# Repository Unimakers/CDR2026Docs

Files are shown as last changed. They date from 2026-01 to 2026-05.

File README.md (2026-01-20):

---
title: "README & MICRODOC"
layout: default
---
# Documentation de l'association UniMakers pour la CDR2026

Table de contenu:
- [Documentation de l'association UniMakers pour la CDR2026](#documentation-de-lassociation-unimakers-pour-la-cdr2026)
  - [Comment créer une page ?](#comment-créer-une-page-)
  - [Comment afficher un modèle 3D](#comment-afficher-un-modèle-3d)

## Comment créer une page ?

Allez dans le dossier correspondant au thème de la page, 

exemple pour l'élec du robot principal: Robot/Elec/

Créez un nouveau fichier pour votre nouvelle page.

Rajoutez en haut du fichier:

```yaml
---
title: "Titre de votre page"
layout: technical
---
```

Utilisez `layout: technical` si vous souhaitez utiliser les modèles 3D ou le visualiseur kicad dans votre page, sinon utilisez `layout: default` pour réduire le temps de chargement de la page en supprimant les imports inutiles.

Les clés de définition doivent se trouver entre les deux `---`.
Après le deuxième `---` vous pouvez écrire le contenu de la page **en markdown**.

Vous pouvez rajouter un 
```yaml
has_children: true
```
si vous souhaitez faire de cette page une page de catégorie qui aura donc des sous-pages.

Pour mettre cette page en tant que sous-page dans une catégorie (et non à la racine) vous devez rajouter une clé `parent` et eventuellement une clé `grand_parent`:

La clé `parent` permettra de définir le parent direct de la page, la valeur doit etre le titre de la page parent.

Exemple, si vous créez une page dans la catégorie `Electronique` du `Robot` vous devrez définir la clé `parent` avec la valeur `Electronique`.

La clé `grand_parent` permettra de définir le grand parent de la page, c'est à dire la catégorie racine, la valeur doit etre le titre du grand parent.

Exemple, si vous créez une page dans la catégorie `Electronique` du `Robot` vous devrez définir la clé `grand_parent` avec la valeur `Robot`

Actuellement l'arbre des titres et catégories est:
```
Racine:
|-Présentation
|-Robot:
| |-Mécanique
| |-Stratégie
|-Pami:
| |-Mécanique
| |-Stratégie
|-Electronique
|-Programmation
| |-Déplacement
| |-Détection
```

Exemple pour créer une catégorie `Actionneurs` dans `Mécanique` sous `Robot` et ensuite créer une page `Pince`:

On crée le dossier `Robot/Meca/Actionneurs` (c'est mieux pour la lisibilité de trier les pages dans des dossiers, techniquement on pourrait tout laisser à la racine).

On crée le fichier `Robot/Meca/Actionneurs/Actionneurs.md`:
```md
---
title: Actionneurs
parent: Mécanique
grand_parent: Robot
has_children: true
layout: default
---
# Les actionneurs de notre robot
Le robot a besoin d'actionneurs pour fonctionner
```

On crée le fichier `Robot/Meca/Actionneurs/Pince.md`:
```md
---
title: Pince
parent: Actionneurs
grand_parent: Mécanique
has_children: true
layout: default
---
# La pince du robot
La pince du robot, nécessaire pour attraper.....
```

## Comment afficher un modèle 3D

Assurez vous d'avoir défini `layout: technical` au lieu de `layout: default`.

Dans votre code markdown rajoutez:
```md
<model-viewer alt="Texte de déscription du modèle 3D" src="url / chemin du modèle 3D" ar shadow-intensity="1" camera-controls touch-action="pan-y"></model-viewer>

Ou

{%raw%}{{%include model3D.html alt="Texte de description du modèle 3D" model="url / chemin du modèle 3D"%}}{%endraw%}
``` 
Le modèle 3D **doit** être en format GLTF / GLB.

## Comment utiliser le visionneur KiCad

Assurez vous d'avoir défini `layout: technical` au lieu de `layout: default`.

- Si vous ne souhaitez que le schématique:

Dans votre code markdown rajoutez:
```md
<kicanvas-embed src="chemin/vers/fichier.kicad_sch" controls="basic"></kicanvas-embed>
```

- Si vous souhaitez le schématique ET la PCB;

Dans votre code markdown rajoutez:
```md
<kicanvas-embed controls="full">
<kicanvas-source src="chemin/vers/fichier.kicad_sch"></kicanvas-source>
<kicanvas-source src="chemin/vers/fichier.kicad_pcb"></kicanvas-source>
</kicanvas-embed>
```

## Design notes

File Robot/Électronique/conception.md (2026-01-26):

---
title: "La conception de la carte"
parent: Elec
layout: technical
---
# La conception de la carte

## 1. Introduction à la conception

Cette section a pour objectif de présenter les principes et choix ayant guidé la conception de la carte électronique du robot. Elle se concentre exclusivement sur les aspects liés à la **conception matérielle et architecturale** de la carte, indépendamment de son utilisation ou de son intégration logicielle, qui sont traitées dans d’autres documents.

La carte a été conçue dans le cadre de la Coupe de France de Robotique, avec pour objectif principal de constituer une solution **fiable, compacte et pérenne**, capable d’être réutilisée sur plusieurs années sans modification majeure. Les contraintes mécaniques du robot étant volontairement figées sur le long terme, la conception de la carte s’inscrit dans cette logique de stabilité et de durabilité.

Un choix structurant de cette conception est l’adoption d’une **architecture tout-en-un**. L’ensemble des fonctions auparavant réparties sur plusieurs cartes distinctes (traitement, capteurs, actionneurs, communication et alimentation) est regroupé sur une seule carte électronique. Cette approche vise à réduire la complexité globale du système, à limiter le câblage interne et à améliorer la fiabilité, en particulier dans un contexte de compétition où les vibrations, les chocs et les faux contacts sont des sources fréquentes de défaillance.

La conception repose également sur une **segmentation fonctionnelle claire**, matérialisée par l’utilisation de plusieurs microcontrôleurs spécialisés. Cette répartition permet de découpler les tâches critiques, de simplifier le développement et le débogage, et d’améliorer la robustesse globale du système, tout en conservant une vision centralisée du fonctionnement du robot.

Enfin, la carte a été pensée pour rester **évolutive et maintenable**. Des interfaces d’extension sont prévues afin de permettre l’ajout de fonctionnalités futures sans remise en cause de l’architecture existante. Les choix réalisés lors de la conception privilégient la lisibilité du schéma, la clarté du routage et l’accessibilité des composants critiques, afin de faciliter la compréhension, la maintenance et les évolutions ultérieures.

## 2. Schéma électronique

### a. Présentation du schéma global

Le schéma électronique a été réalisé sous **KiCad** et est volontairement regroupé sur **une seule feuille au format A2**. Ce choix a été fait afin de conserver une **vision globale immédiate** de l’ensemble de la carte, sans navigation entre plusieurs pages, ce qui facilite la compréhension, la relecture et la maintenance du schéma.

Le schéma est organisé en **blocs fonctionnels clairement délimités**, chaque bloc correspondant à une partie précise de la carte (alimentation, microcontrôleurs, drivers, communication, LED, connecteurs, etc.). Cette organisation visuelle permet d’identifier rapidement le rôle de chaque sous-ensemble tout en conservant une cohérence globale.

Les interconnexions entre les différents blocs sont réalisées à l’aide de **labels globaux**, limitant l’encombrement visuel et améliorant la lisibilité du schéma, tout en restant cohérentes avec le routage du PCB.

### b. Description par parties

#### Alimentation

L’alimentation de la carte repose sur une **distribution en 24/12/5/3.3 V**, qui constitue les tensions centrales du système. Ces tensions sont générées à partir de la batterie via des **convertisseurs de puissance** de type :
- **TSR 2433 / TSR 2450**
- **TEN 50-2411 / TEN 50-2412**

Un convertisseur est dédié spécifiquement à l’**alimentation de la logique**, afin d’assurer une tension stable pour les microcontrôleurs et les circuits de communication.

Les masses sont **communes**, ce qui simplifie la conception tout en assurant une référence électrique cohérente sur l’ensemble de la carte.

Le découplage est principalement assuré **au plus proche des charges**, notamment au niveau des moteurs pas à pas, des servomoteurs et des pompes, afin de limiter les effets des appels de courant et des perturbations générées par les charges inductives.

#### Traitement

La partie traitement repose sur **trois microcontrôleurs** de type **XIAO ESP32-S3** :
- deux XIAO ESP32-S3+,
- un XIAO ESP32-S3.

Chaque microcontrôleur dispose de ses propres lignes de **reset et de boot**, permettant une programmation et un débogage indépendants.

L’alimentation des microcontrôleurs est assurée par le convertisseur dédié à la logique, garantissant une tension stable et isolée des perturbations liées à la puissance.

Même si la hiérarchie maître/esclave n’est pas explicitement matérialisée sur le schéma, les liaisons internes et le découpage fonctionnel traduisent le rôle central du microcontrôleur principal dans la coordination du système.

#### Communication

Les communications internes reposent sur des **liaisons UART point à point**, représentées sur le schéma à l’aide de **labels globaux**, reliant le microcontrôleur principal aux microcontrôleurs dédiés aux capteurs et aux actionneurs.

Un **bus I²C** est également présent et clairement identifié par des labels. Les résistances de **pull-up I²C sont intégrées directement sur la carte**, ce qui permet une utilisation immédiate du bus sans ajout externe.

La communication sans fil est rendue possible par un **module XBee optionnel**, connecté via un **connecteur câblé**. Ce module n’est pas indispensable au fonctionnement du robot, mais permet la transmission d’informations et le paramétrage avant match.

Les interfaces de communication et les connecteurs externes sont regroupés dans des zones dédiées du schéma, facilitant leur identification et leur intégration sur le PCB.

#### Puissance

La partie puissance inclut la gestion directe des actionneurs du robot. Les **moteurs pas à pas** sont pilotés par des **drivers TMC2209**, intégrés directement sur la carte. Ce choix a été motivé par :
- la simplicité d’utilisation,
- les habitudes de l’équipe,
- le fonctionnement silencieux de ces drivers.

Les **servomoteurs et les pompes** sont commandés directement par la carte, sans étage intermédiaire spécifique. Aucune protection active dédiée aux charges inductives n’est intégrée, la conception reposant principalement sur le découplage et la gestion logicielle des activations.

Les éléments de puissance sont regroupés dans des zones dédiées du schéma, clairement séparées des parties logiques et de communication, afin de limiter les interactions et de faciliter la compréhension de l’architecture.

### c. Choix des composants principaux

#### Microcontrôleurs

Le choix des XIAO ESP32-S3 repose principalement sur les **habitudes de l’équipe** ainsi que sur la **disponibilité du matériel** déjà possédé par l’association. L’utilisation de trois microcontrôleurs permet d’augmenter le nombre de cœurs disponibles et de **programmer chaque microcontrôleur indépendamment**, ce qui simplifie la compréhension, le développement et le débogage du code.

Ces microcontrôleurs sont considérés comme **critiques** dans la conception, leur défaillance entraînant l’arrêt du système.

#### Drivers moteurs

Les drivers **TMC2209** ont été sélectionnés pour leur facilité d’intégration, leur fiabilité et leur fonctionnement silencieux. Ils sont directement implantés sur la carte afin de réduire le câblage et d’améliorer la robustesse globale du système.

#### Écran

L’interface utilisateur repose sur un **écran tactile TFT utilisant une communication SPI**. L’écran ne génère pas de contrainte particulière au niveau du schéma électronique et reste **optionnel**. En cas d’absence ou de défaillance de l’écran, le système peut fonctionner en mode dégradé grâce aux boutons physiques prévus sur la carte.

## 3. Conception du PCB

### a. Dimensions et forme de la carte
- Forme générale de la carte
- Dimensions
- Contraintes d’intégration mécanique
- Orientation dans le robot

### b. Règles de routage spécifiques
- Organisation générale du routage
- Autoroute centrale pour les signaux
- Gestion et continuité du plan de masse
- Séparation des zones de puissance
- Zone dédiée au **24 V**

### c. Placement des composants critiques
- Écran
- Microcontrôleurs
- Connecteurs d’extension I²C
- Justification des placements

### d. Connecteurs
- Connecteurs servomoteurs
- Connecteurs GPIO
- Connecteurs d’extension
- Connecteur d’alimentation
- Choix des types de connecteurs

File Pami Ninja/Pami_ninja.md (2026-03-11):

---
title: "Pami Ninja"
layout: technical
nav_order: 1
has_children: true
---

# Présentation Technique : Le PAMI Ninja (Saison 2026)

## 1. Introduction
Le **PAMI Ninja** (Petit Actionneur Mobile Indépendant) est une unité robotique autonome auxiliaire conçue pour opérer spécifiquement dans la zone surélevée du terrain : **le Grenier**. 

Complémentaire au robot principal, il joue un rôle stratégique crucial en manipulant les ressources en hauteur pour maximiser le score de l'équipe grâce à sa grande agilité et son système de préhension par le vide.

---

## 2. Missions et Objectifs Stratégiques
Le PAMI Ninja est spécialisé dans la manipulation de haute précision en espace restreint. Ses objectifs sont hiérarchisés comme suit :

* **Libération des ressources :** Vidage des quatre "frigos" du grenier pour rendre les caisses de noisettes accessibles aux robots au sol.
* **Substitution symbolique :** Remplissage des frigos avec des caisses vides (noires) récupérées dans les zones de chargement.
* **Action finale "À table !" :** En fin de match, ralliement du garde-manger pour valider les points d'occupation ou activation du mécanisme symbolique.

---

## 3. Spécifications et Contraintes
Pour garantir son homologation, le PAMI Ninja respecte strictement les limites fixées par le règlement de la CDR 2026 :

### 3.1 Gabarit et Mobilité
* **Configuration au départ :**
    * Périmètre max : **600 mm**
    * Hauteur max : **150 mm**
* **Configuration en match (déployé) :**
    * Périmètre max : **700 mm**
    * Hauteur max : **350 mm**

### 3.2 Caractéristiques Physiques
* **Masse :** Limite stricte de **1,5 kg**.
* **Énergie :** Alimentation autonome avec protection intégrée pour batterie LiPo.
* **Intelligence :** Système d'évitement d'obstacles embarqué et autonomie décisionnelle totale.

---

## 4. Environnement de Jeu et Valorisation
Le PAMI Ninja évolue dans un écosystème spécifique où chaque action est déterminante pour le score final.

### 4.1 Zone d'évolution
* **Le Grenier :** Une surface de 45 \ 180 cm interdite aux robots principaux.
* **Zone de départ :** Un carré de 20 \ 20 cm situé en hauteur, imposant un design compact dès le déploiement.

### 4.2 Barème de points (Extraction & Remplissage)
**Calcul des points :**
* Chaque frigo vidé : **+2 points**
* Chaque frigo rempli (caisses vides) : **+5 points**

*Note : Ces points sont comptabilisés pour les deux équipes lors du bilan de fin de match.*

---

## 5. Architecture de l'Unité
Le PAMI Ninja est décomposé en trois modules principaux détaillés dans cette documentation :
1.  **Mécanique :** Châssis modulaire MakerBeam et système de ventouse.
2.  **Électronique :** Gestion de la puissance et capteurs de proximité.
3.  **Programmation :** Algorithmes de navigation et logique d'état.

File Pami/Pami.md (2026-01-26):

---
layout: technical
title: Pami
has_children: true
nav_order: 1
---
# Nos PAMIs

<model-viewer alt="PAMI" src="./Meca/FichiersGLTF/ExportPAMIUniWIP.glb" ar style="width:80%; height:400px" shadow-intensity="1" camera-controls min-field-of-view="2deg"></model-viewer>

## Qu'est-ce qu’un PAMI ?

Un **PAMI**, ou *Petit Actionneur Mobile Indépendant*, est un petit robot **autonome** utilisé en complément du robot principal pendant un match. Il peut être lancé au début ou en cours de partie, et il doit être capable de se déplacer par lui-même, même s’il peut être aidé ou contrôlé par les robots de son équipe pendant le match.

Comme les robots classiques, un **PAMI** doit respecter des règles strictes de sécurité et de construction : système d’arrêt d’urgence, détection d’obstacles, sécurité des batteries, etc. Il doit aussi pouvoir fonctionner quelle que soit la couleur de l’équipe.

Un **PAMI** ne suffit pas à lui seul pour homologuer une équipe, mais il doit être homologué pour avoir le droit de participer à un match. Si le robot principal ne peut pas rouler, les PAMIs peuvent quand même jouer seuls, à condition que tout soit homologué et que le robot principal soit present mas static.

## Quel est son role ?

Chaque année, les PAMIs ont des rôles différents, mais leur objectif reste le même : rapporter des points supplémentaires à l’équipe.

Pour cette édition, il existait deux types de PAMIs :

- **La Superstar**

    La Superstar devait monter sur la scène et avancer le plus loin possible dessus pour marquer un maximum de points. Une fois bien placée, elle pouvait activer un actionneur pour « danser ».

- **Les Groupies***

    Les Groupies, quant à elles, devaient se positionner dans des zones spécifiques situées juste devant la scène. Elles aussi pouvaient activer un actionneur pour effectuer une danse.

- **Système de points lié aux PAMIs**

    **5** points sont accordés par Groupie présente dans la zone de fosse (devant la scène) à la fin du match.

    **5** points supplémentaires sont donnés si la Superstar est sur la scène à la fin du match.

     Enfin, **10** points bonus sont attribués si tous les PAMIs dansent ensemble à la fin du match ("font la fête").

## Contraintes techniques

| Critère |  Valeur |
|---|---|
| 📦 **Taille max au départ**  | `150 mm × 450 mm` |
| 📏 **Hauteur** | entre `60 mm` et `150 mm` |
| ⚖️ **Masse maximale** | `1,5 kg` |
| 🎯 **Zone autocollant** | `30 mm × 30 mm` (visible en vue de dessus) |
| 🚀 **Déploiement autorisé** | jusqu’à `+100 mm` en périmètre, `350 mm` en hauteur |
| 🔋 **Autonome** | Déplacement + action sans contact direct |

si vous vouler plus d'information voici le lien en direction des diferents reglement:     
<a href="https://www.eurobot.org/wp-content/uploads/2024/10/Eurobot_General_Rules.pdf" target="_blank">
  Description
</a>

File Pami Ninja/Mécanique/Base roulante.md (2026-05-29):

---
title: "Base roulante"
layout: technical
grand_parent: Pami Ninja
parent: Mécanique
---

# Section mécanique : Base roulante

## 1. Philosophie de conception
La base roulante du **PAMI Ninja** a été conçue pour offrir un compromis idéal entre **rigidité structurelle**, **précision de déplacement** et **accessibilité technique**. 

Initialement, nous avions envisagé un châssis monobloc en impression 3D. Cependant, pour faciliter l'intégration des composants et la maintenance sur le terrain, nous avons opté pour une structure modulaire en **MakerBeam**.

<model-viewer alt="premier prototype" src="../model/premier_prototype.glb" ar style="width:80%; height:400px" shadow-intensity="1" camera-controls min-field-of-view="2deg"></model-viewer>

*Premier design de chassis*

<model-viewer alt="base en MakerBeam" src="../model/makerbeam.gltf" ar style="width:80%; height:400px" shadow-intensity="1" camera-controls min-field-of-view="2deg"></model-viewer>

*Base en MakerBeam*

---

## 2. Structure et Châssis
Le squelette du robot repose sur des profilés en aluminium de 10 \ 10 mm (MakerBeam).

### 2.1 Avantages du système MakerBeam
* **Modularité :** Permet d'ajuster la position des capteurs et des supports sans réimprimer de pièces.
* **Robustesse :** L'aluminium offre une rigidité bien supérieure au plastique face aux collisions éventuelles.
* **Maintenance :** Les faces en acrylique sont fixées via des **vis à tête carrée** glissées dans les rainures et maintenues par des écrous standards. 

> **Accessibilité :** Chaque face est démontable en dévissant simplement 8 écrous, permettant un accès complet à l'électronique interne en moins de 30 secondes sans fragiliser la structure porteuse.

---

## 3. Motorisation et Cinématique
La base utilise une configuration à deux roues motrices classiques avec des moteurs pas-à-pas.

| Composant | Détails techniques |
| :--- | :--- |
| **Moteurs** | Moteurs pas-à-pas (Stepper) pour une précision millimétrée |
| **Transmission** | Montage en **prise directe** sur l'axe moteur (évite le backlash) |
| **Type de roues** | Roues classiques en silicone à haute adhérence |
| **Support** | Fixation directe sur la plaque inférieure du châssis |

### 3.1 Intégration du système de préhension
La face avant présente une particularité : un évidement a été pratiqué dans la MakerBeam supérieure. Ce passage est dédié au **mécanisme de la ventouse**, permettant au bras et au tuyau de vide de se déployer vers l'extérieur pour manipuler les éléments de jeu.

---

## 4. Analyse de Masse et Stabilité
L'un des défis majeurs pour un PAMI est sa stabilité lors des phases d'accélération et de freinage brusques.

* **Centre de Gravité bas :** En fixant les moteurs (les composants les plus lourds) directement sur la plaque inférieure, nous abaissons au maximum le centre de gravité.
* **Répartition des masses :** Le choix de l'aluminium pour le cadre et de l'acrylique pour les parois permet de garder une structure légère en périphérie tout en concentrant le poids au niveau du plancher.
* **Impact dynamique :** Cette configuration réduit le moment d'inertie et limite l'effet de "tangage" lors des changements de direction, garantissant que la ventouse reste alignée avec sa cible.

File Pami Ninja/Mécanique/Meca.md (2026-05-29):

---
title: "Mécanique"
layout: technical
parent: "Pami Ninja"
nav_order: 2
has_children: true
---

# Partie mécanique du PAMI Ninja

Le PAMI Ninja est constitué de deux sous-ensembles mécaniques principaux. Le premier est une base roulante assurant le déplacement du robot et l’intégration des composants nécessaires à son fonctionnement. Le second correspond aux actionneurs, qui permettent d’interagir avec les éléments présents dans le grenier. Une description détaillée de ces deux parties sont accessible via le menu déroulant situé à gauche.

Voici à quoi ressemble le PAMI Ninja dans son ensemble:
<div style="display: flex; justify-content: space-around; flex-wrap: wrap;">
<model-viewer alt="premier prototype" src="../model/assemblage_pami_ninja.gltf" ar style="width:80%; height:400px" shadow-intensity="1" camera-controls min-field-of-view="2deg"></model-viewer>
</div>

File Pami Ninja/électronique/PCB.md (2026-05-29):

---
title: "PCB"
layout: technical
grand_parent: Pami Ninja
parent: Électronique
has_children: false
---

Voici le PCB de notre carte électronique ci dessous:

<kicanvas-embed controls="full">
<kicanvas-source src="../électronique/pcb&schéma/carte_pami_ninja.kicad_pcb"></kicanvas-source>
</kicanvas-embed>

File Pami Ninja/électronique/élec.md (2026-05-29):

---
title: "Électronique"
layout: technical
parent: "Pami Ninja"
nav_order: 2
has_children: true
---

# Électronique

La partie électronique parle de la carte que nous avons dû concevoir pour faire fonctionner le PAMI Ninja. Cette partie est décomposée en deux éléments qui sont accessible via le menu déroulant situé à gauche :

- Le schéma électrique réalisé sur le logiciel KiCad.
- Le PCB (circuit imprimé) qui permet le fonctionnement de la carte.

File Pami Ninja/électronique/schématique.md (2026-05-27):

---
title: "Schématiques"
layout: technical
grand_parent: Pami Ninja
parent: Électronique
has_children: false
---

# Conception du Schématique Électronique

## 1. Présentation générale

Avant de dessiner physiquement la carte (le PCB), on a réalisé le **schématique** sur le logiciel **KiCad**. Cette étape constitue le plan logique du circuit, permettant de définir les composants à utiliser ainsi qu'à visualiser les différentes connexions entre eux.

Pour garantir la fiabilité du système, on s'est appuyé sur la documentation des anciennes cartes de l'association ainsi que sur l'accompagnement des professeurs du MakerSpace.

Voici donc le dit schématique:

<kicanvas-embed controls="full">
<kicanvas-source src="../électronique/pcb&schéma/carte_pami_ninja.kicad_sch"></kicanvas-source>
</kicanvas-embed>

## 2. Architecture du circuit 

Pour rendre le schéma plus clair et modulaire, on a fait le choix de le découper en plusieurs blocs fonctionnels. Chacun a un rôle précis dans le fonctionnement du PAMI Ninja :

* **Batterie :** Ce bloc gère l'arrivée directe de l'énergie. C'est le point d'entrée de la puissance générale de la carte qui sera ensuite distribuée et régulée.
* **Microcontrôleur :** Bien qu'il ne soit pas enfermé dans un bloc visuel, c'est le cœur du système (basé sur un module ESP32). Il centralise toutes les connexions logiques : il exécute le programme de match, traite les données reçues des capteurs et donne les ordres d'action.
* **Driveurs moteur pas à pas :** Cette partie gère l'interface de puissance pour les mouvements. Elle permet au microcontrôleur de piloter les moteurs des roues avec précision pour assurer les déplacements du robot sur le plateau.
* **Pompe :** Ce bloc est dédié spécifiquement à la gestion du système de la pompe de notre robot. Il commande l'activation de la pompe nécessaire à la préhension des caisses de noisettes par la ventouse.
* **Actionneurs :** Ce bloc regroupe la commande des autres éléments mécaniques mobiles, comme le capteur à ultrasaon qui permets de détecter si quelque chose se rapproche afin d'éviter toute collision ou comme la tirette qui nous permettra de mettre en route nos robots à chaque début de match.
* **Extensions :** Ce bloc permet d'ajouter des fonctionnalités supplémentaires ou des capteurs externes comme le servo moteur permettant de gérer l'inclinaison du bras. Il offre une flexibilité pour faire évoluer le robot sans modifier le cœur de la carte.

## 3. Réflexion technique

L'étude des versions précédentes a mis en avant l'importance d'avoir un schéma propre et bien compartimenté. Cette organisation permet de ne pas surcharger la vue globale et de limiter les erreurs de câblage lors de la conception.

Grâce aux conseils des professeurs, on a pu s'assurer que l'isolation entre les blocs de puissance et la logique était bien respectée. Cette rigueur dans la conception du schématique est indispensable pour que le robot soit robuste et qu'il ne subisse pas d'interférences durant les 90 secondes de match.

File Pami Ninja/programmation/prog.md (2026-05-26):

---
title: "Programation"
parent: "Pami Ninja"
layout: technical
---

# Programation

## Introduction

Ce code contrôle un robot mobile pour une compétition (type Coupe de Robotique / Eurobot).  
Il gère :

- Deux moteurs pas à pas avec driver (TMC2209 ou similaire)
- Un servo-moteur sur PCA9685
- Une pompe et une électrovanne via PCF8574
- Une tirette de démarrage
- Un interrupteur de côté (Jaune / Bleu)

Le robot exécute une stratégie autonome une fois la tirette retirée.

---

## Configuration Matérielle

### Broches ESP32

| Broche | Définition | Fonction | Commentaire |
|---|---|---|---|
| GPIO2  | `STEP_D` | Step moteur droit | |
| GPIO1  | `DIR_D` | Direction moteur droit | |
| GPIO4  | `STEP_G` | Step moteur gauche | |
| GPIO3  | `DIR_G` | Direction moteur gauche | |
| GPIO9  | `EN_PIN` | Enable moteurs | LOW = actif |
| GPIO8  | `TIRETTE` | Tirette de démarrage | LOW = présente |
| GPIO7  | `SWITCH` | Interrupteur côté | LOW = Jaune |

**I2C** : SDA = GPIO5 (D4), SCL = GPIO6 (D5)

### Périphériques I2C

- **PCA9685** : Adresse `0x40` → Contrôle du servo (canal 0 - J13)
- **PCF8574AT** : Adresse `0x20` → Contrôle Pompe + Électrovanne

---

## Bibliothèques Utilisées

```cpp
#include <Arduino.h>
#include <Wire.h>
#include <Adafruit_PWMServoDriver.h>

C++

#define VITESSE_MOTEUR 800        // Microsecondes entre pas (plus bas = plus rapide)
#define NB_MINI_PAS 5

// Calibration odométrie (calibrée sur le terrain)
#define STEPS_PER_REV     3232
#define WHEEL_CIRC_CM     45.87f
#define WHEELBASE_CM      8.20f

#define CM_EN_PAS(cm)     ((int)((float)(cm) / WHEEL_CIRC_CM * STEPS_PER_REV))
#define DEG_EN_PAS(deg)   ((int)((float)(deg) / 360.0f * (float)M_PI * WHEELBASE_CM / WHEEL_CIRC_CM * STEPS_PER_REV))
```

# Fonctions de Contrôle

1. **Pompe et Électrovanne** (PCF8574)

    Le PCF8574 est en open-drain : écrire 0 = actif (LOW), écrire 1 = inactif.
    void pompeOn();
    void pompeOff();
    void evOn();
    void evOff();

2. **Servo** (PCA9685)

    #define SERVO_J13_CH 0
    #define SERVO_MIN 150
    #define SERVO_MAX 500
    void setServoAngle(int angle); // Angle entre 0 et 180°
    updateServoFromSwitch(); // Position selon l'interrupteur

3. **Mouvements de Base**

La fonction **rotate()** intègre une rampe d’accélération / décélération pour plus de fluidité et de précision.

* avancer(steps) / avancerCm(float cm)

* reculer(steps) / reculerCm(float cm)

* tournerDroite(steps) / pivoterDroite(float deg)

* tournerGauche(steps) / pivoterGauche(float deg)

* Stratégies
  Deux stratégies miroirs sont implémentées en fonction du coté sur lequel on était :

  * strategieJaune()

  * strategieBleu()

  Le choix est fait automatiquement selon l’état de l’interrupteur SWITCH.
  Chaque stratégie contient :

* Petite manœuvre de départ

* Séquence de déplacements précis (avances, reculs, rotations)

* Actions finales avec le servo

* Boucle infinie d’oscillation du servo en fin de match (effet visuel / signal)

## Fonction setup()

* Initialisation de la communication I2C (Wire.begin(5, 6))

* Configuration du PCA9685 (fréquence 50 Hz)

* Configuration des broches GPIO

* Scan complet du bus I2C (affiché dans le moniteur série)

* Mise à l’état initial : pompe et EV éteintes, servo à 90°

* Initialisation du PCF8574 (toutes sorties relâchées)

## Fonction loop()
Fonctionnement classique d’un robot de compétition :

1. Mise à jour continue de la position du servo selon l’interrupteur

2. Attente de la tirette

3. Détection du côté (Jaune ou Bleu)

4. Exécution de la stratégie correspondante

5. Attente de remise de la tirette pour permettre un nouveau départ

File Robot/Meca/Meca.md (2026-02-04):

---
title: "Mécanique"
parent: "Robot"
layout: technical
---
## Le châssis 🧰

### La Base 🛠️
Pour la base du robot, nous avons opté pour un châssis différentiel, c'est à dire un châssis à deux roues motrices. Ce type de châssis est plus simple à mettre en œuvre et plus facile de prise en main, aussi bien pour nous que pour les étudiants de première année car il offre une excellente maniabilité, notamment pour réaliser des rotations sur place et des déplacements précis sans nécessiter une mécannique complexe.

### La Compartimentation 🧩
La structure extérieur du châssis étant complétée, nous avons choisi de le compartiementer en plusieurs espaces distincts :

#### Compartiments 📦 :

- 
- 
- 
<div style="display: flex; justify-content: center; margin-top: 20px;">
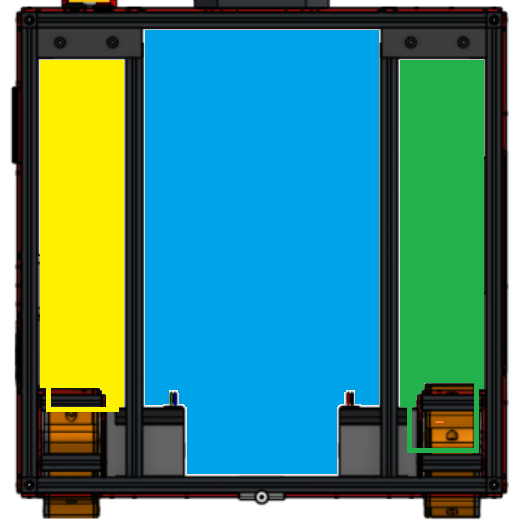
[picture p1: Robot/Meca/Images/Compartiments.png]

</div>

## La batterie 🔋

### Choix de la batterie ⚡
Nous avions d’abord prévu d’utiliser des cellules Lithium Fer Phosphate (LiFePO4) en pack maison, car elles sont réputées stables. Malheureusement, les cellules que nous avions en stock se sont révélées en très mauvais état : plusieurs étaient mortes, d’autres fortement gonflées, et l’ensemble présentait des risques réels. De plus, ces batterie demande de l'entretient pour rester stable et efficace.

Face à ces soucis, nous avons abandonné complètement l’idée d'une batterie LiFePO4 brut. Nous avons opté pour une batterie Greenworks 24 V 3.5 Ah. Ce choix s’est imposé pour plusieurs raisons : la tension de 24 V convient parfaitement pour alimenter efficacement nos deux moteurs stepper, la batterie est déjà sécurisé d’origine et il ne demande quasiment aucun entretien.
De plus greenwork est l'une des seules marques à faire des batterie 24V dans le format pour des perceuses/visseuses électriques. Pour comparer les batteries Makita; DeWalt et Boch travaillent majoritairement en 18V.
C’est un compromis pragmatique, économique et fiable.
<br>
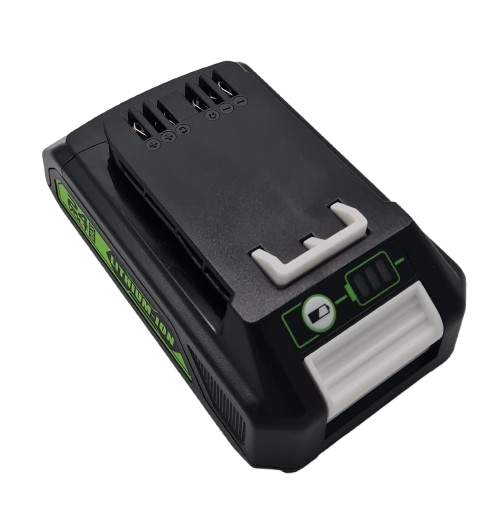
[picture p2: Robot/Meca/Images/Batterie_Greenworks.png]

<br>
<sub>Batterie Greenworks 24V (3.5 Ah)</sub> 

### Le support de batterie 🔧
La batterie, étant déjà conditionnée, nécessite un support pour être correctement maintenue et connectée à la carte électronique du robot.

Le support a été conçu en prenant comme référence le chargeur de la batterie afin d'assurer un alignement précis. Un rail guide les ports de connexion, tandis qu’une cale rétractable se bloque dans une encoche prévue à cet effet. Cette conception garantit que la batterie reste solidement en place, même si le robot est retourné, et qu’elle ne peut être retirée que lorsque la cale est rétractée.

Enfin, un système de pivotement d’environ 45° a été ajouté afin de permettre l’insertion de la batterie à la verticale et son extraction en biais, rendant la manipulation plus simple et ergonomique.
La batterie est également maintenue en position grâce à des aimants, fixés sur des supports latéraux venant se fixer directement sur les profils MakerBeam du robot. Ce dispositif assure une tenue fiable tout en facilitant la mise en place et le retrait de la batterie.
<br>
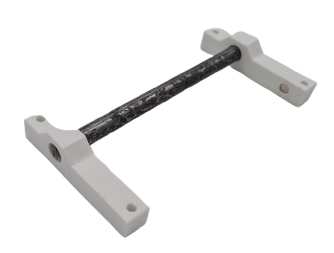
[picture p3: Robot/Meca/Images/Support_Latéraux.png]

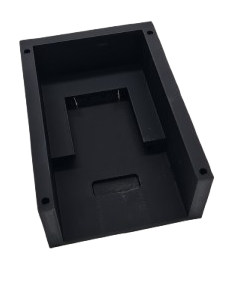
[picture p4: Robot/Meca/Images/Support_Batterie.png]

<br>

### Connecteur de la batterie 🔌
La batterie Greenworks utilise un connecteur propriétaire qui n’est pas facilement remplaçable par des contacts standards. Nous avons cherché des lamelles à lame ressort compatibles, mais aucune solution fiable, robuste et disponible rapidement n’a été trouvée sur le marché.

Nous avons donc utilisé des cosses électriques plates fixées directement sur le compartiment batterie. Cette solution fonctionne techniquement : la connexion tient bien en fonctionnement normal. Cependant, elle présente deux inconvénients pratiques importants : il faut maintenir les cosses à la main lors de l’insertion de la batterie, et il faut aussi les guider / maintenir lors du retrait. Cela rend l’opération peu rapide et pas très ergonomique. De ce faites le support de batterie intègre un système de maintient des cosses électriques en place. 
<br>
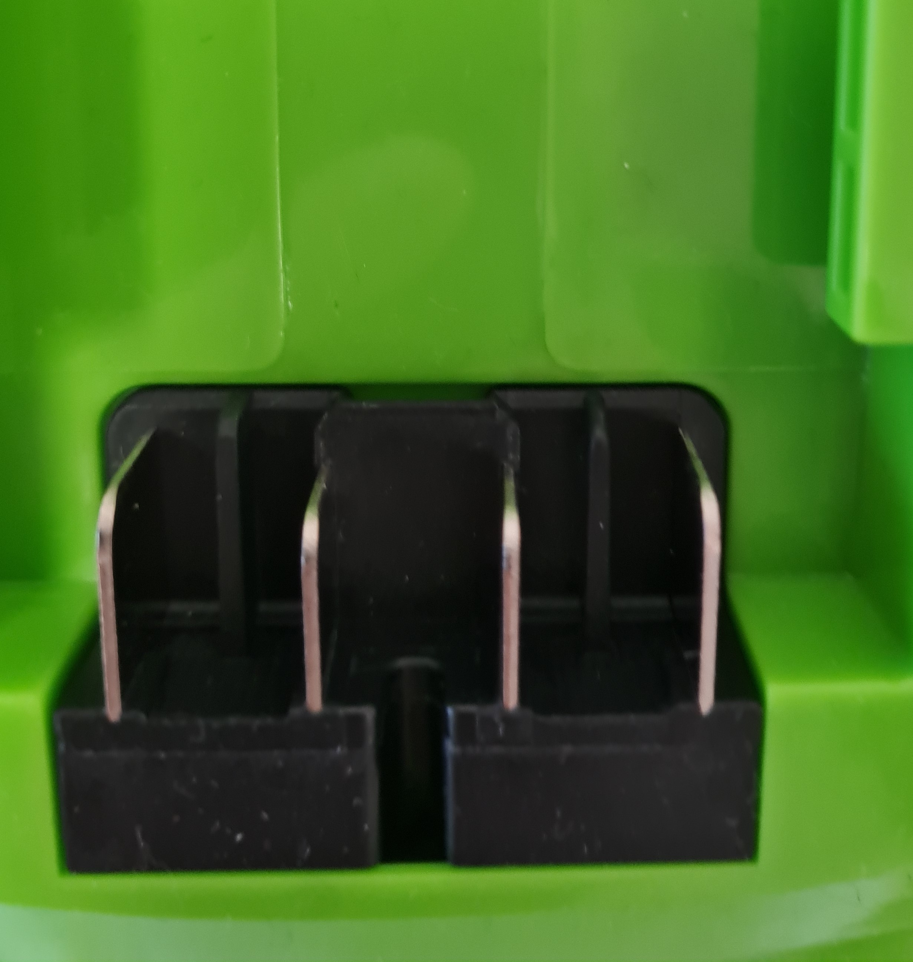
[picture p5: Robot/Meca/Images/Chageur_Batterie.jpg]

➡️
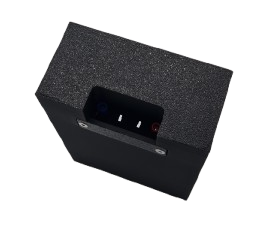
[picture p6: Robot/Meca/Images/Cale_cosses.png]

<br>
## Les actionneurs 

❌ **La suite de cette documentation n'est pas à jour.**

### Les planches

L'actionneur chargé de soulever les planches avait été imaginé avec des ventouses. Celles-ci, accrochées par paires à l'extrémité de deux bras articulés, étaient reliées à des pompes sur la face arrière du robot. 
<div style="display: flex; justify-content: space-around; flex-wrap: wrap;">

</div>

### Les conserves

Pour les boites de conserve, l'action se faisait en se basant sur le magnétisme de celles-ci. Incrémentée de petits aimants permanents, la sorte de pince se déplace de haut en bas sur un rail pour soulever les éléments de jeux. 
Pour avoir une idée du processus de conception de cet actionneur, vous retrouverez ci-dessous l'image de la première version : 

<div style="display: flex; justify-content: space-around; flex-wrap: wrap;">

</div>

On retrouve dès le départ l'idée d'utiliser le magnétisme. Cependant, ce fonctionnement des servomoteurs en direct posait problème.

En effet, l'actionneur arrière n'est pensé que pour une planche ; la seconde devait être portée par l'actionneur conserve. Nous avons par conséquent décidé de déplacer les servos à l'arrière pour arriver au rendu final suivant :

<div style="display: flex; justify-content: space-around; flex-wrap: wrap;">

</div>

Ce modèle beaucoup plus abouti permet une utilisation fiable des aimants et une mise en place simple de la stratégie permettant de réaliser sans difficultés des gradins de niveaux 1 et 2, et est théoriquement suffisamment puissant pour venir construire un gradin de niveau 3, même si cela n'a jamais réussi en match.

### La banderole

La banderole est le dernier actionneur réalisé ; celle-ci a été pensée pour être positionnée sur l'actionneur conserve.

Déposer en début de match sur la bordure un élastique assure une tension suffisante au bon déploiement de la banderole.
<div style="display: flex; justify-content: space-around; flex-wrap: wrap;">


</div>
___

## La détéction

Équipé d'un lidar situé au sommet du robot, celui-ci nous offre une détection à 360 degrés ainsi qu'un retour sur l'angle et la distance nous permettant de réagir rapidement lorsqu'un adversaire s'approche trop.

<div style="display: flex; justify-content: space-around; flex-wrap: wrap;">

</div>

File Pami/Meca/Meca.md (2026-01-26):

---
title: "Mécanique"
parent: "Pami"
layout: technical
---

# La mécanique des PAMIs

La mécanique des PAMIs s’appuie sur plusieurs éléments essentiels qui travaillent ensemble pour assurer leur déplacement, leur autonomie et leur sécurité pendant le match. Voici leur fonctionnement organisé de façon logique :

## 1. La tirette de démarrage
La tirette est un élément clé qui déclenche le début du match. En la retirant, on lance le code de contrôle du PAMI, ce qui active son fonctionnement. C’est un dispositif de sécurité important pour éviter tout démarrage intempestif.

### Comment ça fonctionne ?

#### 1. Composants utilisés
🔹 Un aimant : fixé sur une "tirette" (petite languette ou support que tu peux retirer à la main).

🔹 Un capteur magnétique : souvent un capteur à effet Hall ou un reed switch, placé sur le robot.

#### 2. Principe
🔹 Quand l’aimant est proche du capteur, celui-ci détecte le champ magnétique.

🔹 L’état du capteur est alors actif (souvent une tension logique "1" ou "0", selon le montage).

🔹 Quand on retire la tirette (donc l’aimant), le champ magnétique disparaît.

🔹 Le capteur détecte ce changement et déclenche une action dans le programme, typiquement :
 → Lancement du robot, démarrage du code, mise sous tension, etc.

## 2. Le bouton d’arrêt d’urgence
Le bouton d’arrêt d’urgence (BAU) est un dispositif de sécurité obligatoire sur tous les robots et PAMI. Il permet de couper immédiatement l’alimentation du système en cas de danger ou de dysfonctionnement. Il fonctionne comme un interrupteur mécanique : lorsqu’on appuie dessus, le circuit électrique est interrompu.

### Comment ça fonctionne ?
Dans notre cas, on l’utilise aussi comme interrupteur principal :

🔹 Lorsqu’il est enfoncé (position d’arrêt), le PAMI n’est pas alimenté.

🔹 Pour le démarrer, on relève le bouton d’arrêt d’urgence (on “lève le BAU”), ce qui libère le courant et alimente le système.

🔹 En fin d’utilisation ou pour l’arrêter rapidement, on appuie à nouveau sur le bouton pour le couper.

C’est donc à la fois un mécanisme de sécurité et un interrupteur de mise sous tension dans notre configuration.

## 3. Le switch de sélection d’équipe
Un petit interrupteurqui  permet de sélectionner la couleur de l’équipe (bleu ou jaune). Cette sélection influence le comportement du PAMI en choisissant, dans le code, la stratégie adaptée à l’équipe.

## 4. L’alimentation et la batterie
Une batterie compacte qui fournit l’énergie nécessaire à tous les composants : moteurs, servomoteurs, capteurs. C’est grâce à cette source d’énergie que le PAMI peut fonctionner de façon autonome.

## 5. Les roues
Les PAMIs sont équipés de deux roues motrices, placées au centre du robot, de part et d’autre de son châssis. Cette position centrale permet d’assurer un bon équilibre.
En effet, si les roues étaient placées trop à l’arrière, le robot aurait tendance à pencher vers l’avant, et inversement s’il était trop à l’avant. En les positionnant au centre, on évite ce déséquilibre, ce qui garantit une meilleure stabilité lors des déplacements.

<model-viewer alt="PAMI" src="./FichiersGLTF/roue.glb" ar style="width:80%; height:400px" shadow-intensity="1" camera-controls min-field-of-view="2deg"></model-viewer>

## 6. Les moteurs pas à pas (NEMA 17)
Chaque roue est entraînée par un moteur pas à pas de type NEMA 17. Ces moteurs sont particulièrement adaptés aux déplacements précis, car ils permettent un contrôle angulaire très peécis. Cela rend le robot capable d’effectuer des mouvements maîtrisés, ce qui est essentiel pour se déplacer.

<model-viewer alt="PAMI" src="./FichiersGLTF/moteur.gltf" ar style="width:80%; height:400px" shadow-intensity="1" camera-controls min-field-of-view="2deg"></model-viewer>

### 🧩 Assemblage de la roue et du moteur

🔧 Étapes de l’assemblage mécanique :

🔹 Le moteur pas à pas NEMA 17 est inséré dans une découpe latérale du bloc principal. Ce logement est parfaitement ajusté pour accueillir le moteur de façon stable.



🔹 Une plaque de fixation est ajoutée entre le moteur et le bloc afin de le maintenir en position. Elle est vissée dans le châssis pour empêcher tout mouvement du moteur.

Description

🔹 La roue est fixée directement sur l’arbre du moteur via une vis. Elle est munie d’un roulement à billes en son centre, sur sa face extérieure.

Description

🔹 Une seconde plaque, située de l’autre côté de la roue (côté extérieur), est fixe. Cette plaque accueille le roulement intégré à la roue : ainsi, la roue peut tourner librement grâce au roulement, tandis que la plaque reste immobile.

Description

## 7. Le capteur ultrason
Monté à l’avant du PAMI, ce capteur infrason détecte les obstacles et les distances. Il permet d’adapter la trajectoire du PAMI pour éviter les collisions, aidant ainsi à la navigation autonome.

## 8. Les servomoteurs avant
Enfin, 2 petits servomoteurs sont situés à l’avant et serve a faire bouger un main pour réaliser l'action de danser.

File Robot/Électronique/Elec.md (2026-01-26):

---
title: "L'électronique du robot principal"
parent: Robot
nav_order: 2
has_children: true
layout: technical
---

# Documentation – Carte électronique "Doom"

## 1. Introduction

### a. Objectif de la carte

Cette carte électronique a été conçue dans le cadre de la Coupe de France de Robotique, édition 2026. Elle constitue le cœur électronique du robot principal et a pour vocation de centraliser l’ensemble des fonctions nécessaires à son fonctionnement.

L’un des objectifs majeurs de cette carte est son **utilisation sur plusieurs années**. La structure mécanique du robot étant prévue pour rester inchangée sur le long terme, la carte a été conçue de manière à rester mécaniquement et électriquement compatible d’une saison à l’autre. De la même manière, l’architecture logicielle est pensée pour être stable dans le temps, limitant les évolutions nécessaires entre les différentes éditions de la compétition.

La carte assure de façon autonome la gestion de toutes les actions du robot, notamment :
- la logique de contrôle globale,
- le pilotage des moteurs et des actionneurs,
- la gestion des capteurs,
- la distribution et la régulation de la puissance,
- la communication avec des éléments externes.

Afin de garantir une organisation claire et robuste, les missions sont **segmentées** à l’aide de trois microcontrôleurs distincts :
- un microcontrôleur principal chargé de la supervision globale, de la gestion de l’interface écran et de la coordination des deux autres microcontrôleur.
- un microcontrôleur dédié à la gestion des capteurs,
- un microcontrôleur dédié aux drivers et aux actionneurs,

Cette segmentation permet d’améliorer la lisibilité de l’architecture, la fiabilité du système et la maintenance logicielle. Des ports d’extension I²C sont également prévus afin de permettre l’ajout futur de fonctionnalités sans remise en cause de la carte principale.

### b. Version tout-en-un

La carte présentée dans cette documentation correspond à une **version tout-en-un** regroupant l’ensemble des fonctions auparavant réparties sur plusieurs cartes distinctes. Les architectures précédentes prévoyaient notamment :
- une carte principale,
- une carte drivers,
- une carte dédiée au LIDAR,
- une carte écran,
- une carte d’extension,
- une carte d’alimentation.

Bien que ces cartes aient été entièrement conçues et prêtes pour une mise en production, le choix a été fait de regrouper l’ensemble de ces fonctions sur une seule carte électronique.

Cette approche vise principalement à :
- **simplifier le câblage**, tant pour les signaux logiques que pour la puissance,
- **faciliter l’installation** et l’intégration dans le robot,
- **améliorer la maintenance**, en réduisant le nombre de points de défaillance,
- **augmenter la fiabilité en compétition**, en limitant les faux contacts et les erreurs de branchement.

La carte tout-en-un remplace ainsi l’intégralité des cartes précédemment envisagées. Les connexions ont été rationalisées et standardisées à l’aide de connecteurs Molex et JST pour les signaux, et de connecteurs XT60 pour l’alimentation, garantissant à la fois robustesse et facilité de manipulation.

Ce choix d’architecture permet d’obtenir un système plus compact, plus fiable et plus simple à exploiter, tout en conservant une modularité suffisante pour les évolutions futures.

## 2. Présentation générale

### a. Description générale

La carte électronique présente un format rectangulaire de **98 mm × 171 mm**. Ce gabarit a été défini afin de s’intégrer durablement dans l’architecture mécanique du robot, prévue pour être conservée sur plusieurs saisons. La carte est conçue en **double couche**, permettant un compromis entre compacité, simplicité de routage et maîtrise des coûts de fabrication.

Elle est installée **verticalement dans le sens de la longueur** au sein du robot. Cette orientation facilite l’intégration mécanique, l’accessibilité aux connecteurs ainsi que le refroidissement, la carte étant directement ventilée.

D’un point de vue fonctionnel, la carte centralise l’ensemble des capacités nécessaires au fonctionnement du robot. Elle assure notamment :
- le pilotage de **6 moteurs pas à pas**,
- la commande de **32 servomoteurs**,
- la gestion de **16 pompes**,
- l’interface avec un **LIDAR**,
- la communication et la programmation via des **ports USB** directement reliés aux microcontrôleurs,
- la possibilité d’intégrer un **module XBee optionnel** pour la communication sans fil,
- la gestion d’un **écran tactile** servant d’interface principale,
- la présence de **8 boutons binaires** permettant le paramétrage et le contrôle du robot en cas de défaillance de l’écran.

La carte est également conçue pour rester évolutive. Elle dispose de connecteurs permettant l’ajout :
- d’une carte indépendante communiquant en **UART**,
- de cartes d’extension via le bus **I²C**.

Enfin, la carte intègre la **gestion complète de la puissance**, incluant la régulation, la distribution et les protections électriques nécessaires au bon fonctionnement des différents sous-systèmes du robot.

### b. Contraintes spécifiques à la compétition

L’utilisation en Coupe de France de Robotique impose des contraintes spécifiques liées à l’environnement et au déroulement des matchs. Le robot étant mobile, la carte est soumise à des **vibrations régulières** ainsi qu’à des **chocs ponctuels**, notamment lors de contacts avec les bordures du terrain. Ces contraintes ont été prises en compte dès la conception mécanique et électronique afin d’assurer la fiabilité de l’ensemble.

La carte est installée dans une zone ventilée du robot, éloignée des moteurs, ce qui limite son exposition aux perturbations électromagnétiques, à la poussière et aux projections. Aucune contrainte directe du règlement ne s’applique à la taille de la carte, celle-ci étant uniquement limitée par l’encombrement global du robot.

En termes de fonctionnement, un match de compétition dure **100 secondes**, mais la carte doit rester opérationnelle bien au-delà de cette durée. En pratique, le robot est allumé pendant toute la phase de préparation, pouvant atteindre **jusqu’à 10 minutes**, ainsi que lors des nombreuses phases de test.

Une attention particulière est portée à la **gestion de la consommation électrique**. La présence de nombreux servomoteurs et pompes implique des courants importants, susceptibles de provoquer des chutes de tension lors d’activations simultanées. La carte est donc conçue pour permettre une gestion maîtrisée de ces charges, tant au niveau matériel que logiciel, afin de garantir un fonctionnement stable tout au long des matchs et des essais.

## La carte
<model-viewer alt="carte V1" style="width:80%; height:400px"  src="./image/model_carte.glb" ar shadow-intensity="1" camera-controls touch-action="pan-y"></model-viewer>

## 3. La conception
Si vous souhaitez en apprendre plus la conception de la carte je vous invite à cliquer sur le lien suivant --> [vers conception](./conception.html)
  
<kicanvas-embed controls="full">
<kicanvas-source src="image/doom_v1.kicad_sch"></kicanvas-source>
<kicanvas-source src="image/doom_v1.kicad_pcb"></kicanvas-source>
</kicanvas-embed>
Utilisez shift+mollet, ctrl+mollet ou alt+mollet pour vous déplacez
Un menu est également disponible a droite afin de choisir la couche ou l'opacité des éléments 

## 4. Caractéristiques techniques

### a. Tension et consommation

La carte est alimentée par une **batterie Li-ion de 24 V**, d’une capacité de **3,5 Ah** pour une énergie totale de **84 Wh**. La batterie est reliée à la carte via un **relais commandé par un bouton d’arrêt d’urgence (BAU)**, garantissant une coupure immédiate de l’alimentation du robot en cas de besoin.

À partir de cette tension d’entrée, la carte génère les tensions nécessaires aux différents sous-ensembles du robot :
- **12 V**, utilisé principalement pour l’alimentation des actionneurs,
- **5 V**, destiné aux microcontrôleurs, aux servomoteurs, à certains périphériques et à la logique intermédiaire,
- **3,3 V**, dédié  module d'extension et aux circuits de communication.

Les actionneurs (moteurs pas à pas, servomoteurs et pompes) sont **alimentés directement par la carte**. Aucune protection active spécifique n’est intégrée au niveau de la puissance. La limitation des perturbations électriques repose principalement sur :
- la présence de **condensateurs de découplage** afin de limiter les pics de courant,
- des **diodes de protection** contre les retours de courant, notamment sur les charges inductives.

La consommation électrique de la carte est évaluée de manière globale, en distinguant une consommation nominale et une consommation maximale théorique.

**Hypothèses de calcul :**
- Les servomoteurs utilisés sont des **FS5109M**, pouvant consommer des courants élevés lors des phases de démarrage ou de blocage.
- Les moteurs pas à pas, servomoteurs et pompes ne sont pas tous activés simultanément à pleine charge.
- Le pilotage logiciel limite volontairement l’activation concurrente des actionneurs afin d’éviter des pics de courant susceptibles de provoquer une chute de tension.
- La consommation de la logique (microcontrôleurs, capteurs, communication) reste négligeable devant celle des actionneurs.

Dans ces conditions :
- la **consommation nominale** correspond à un scénario de match classique, avec une activation séquencée des actionneurs,
- la **consommation maximale théorique** correspond à un cas défavorable où plusieurs actionneurs sont sollicités simultanément.

Ces valeurs sont utilisées comme base de dimensionnement de l’alimentation et de la stratégie de gestion de la puissance.

### b. Interfaces de communication interne et externe

La communication interne de la carte repose sur **deux liaisons UART point à point** :
- une liaison entre le microcontrôleur principal et le microcontrôleur dédié aux capteurs,
- une liaison entre le microcontrôleur principal et le microcontrôleur dédié à la gestion des moteurs et des actionneurs.

Le microcontrôleur principal agit comme un **chef d’orchestre**, coordonnant l’ensemble des sous-systèmes, assurant la synchronisation des actions et la cohérence globale du fonctionnement du robot. Aucun débit spécifique n’est imposé à ces liaisons, celles-ci étant configurées en fonction des besoins du système.

La carte expose principalement un **bus I²C** vers l’extérieur afin de permettre l’ajout de cartes d’extension ou de capteurs supplémentaires. Les adresses I²C sont configurables à l’aide de **jumpers à souder**, permettant d’éviter les conflits d’adressage et de conserver une architecture flexible.

Un module de communication **XBee** peut également être ajouté de manière optionnelle via un connecteur dédié. Ce module est utilisé pour :
- la transmission d’informations vers un éventuel centre de calcul,
- le lancement du match (top départ),
- le paramétrage du robot avant match.

Le module XBee est entièrement **optionnel** et n’est pas critique pour le fonctionnement du robot en match. Son absence n’affecte pas le comportement nominal du système.

## 5. Liste des composants et assemblage
  - lien vers assemblage.md

## 6. Maintenance et dépannage
- Problèmes connus
- Remplacement de composants

## 7. Historique des versions
- Version de la carte
- Modifications
- Date
- Responsable

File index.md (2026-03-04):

---
title: Présentation
layout: home
nav_order: 0
---
# La Coupe de France de Robotique

<div style="display: flex; justify-content: space-around; flex-wrap: wrap;">
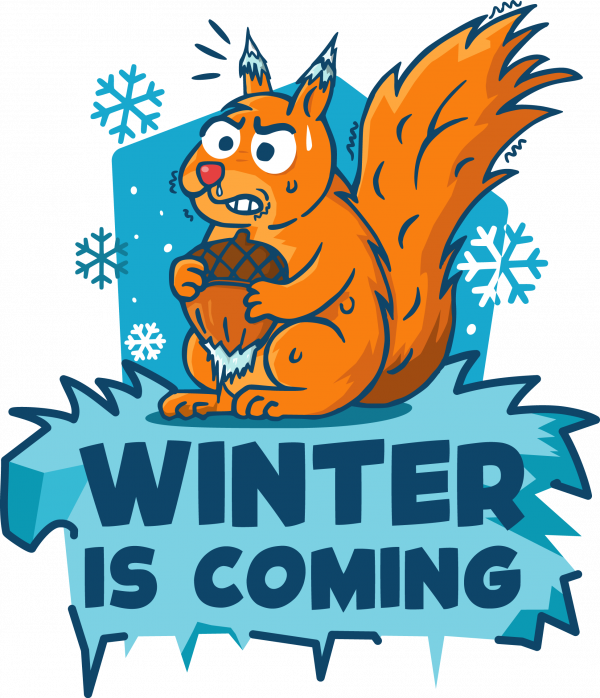
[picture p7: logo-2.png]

</div>

## Un événement unique
La **Coupe de France de Robotique** (souvent abrégée **CDFR**) est **le plus grand événement de robotique amateur en Europe**, organisé chaque année par **Planète Sciences** avec le soutien de nombreux partenaires et bénévoles.

Pour l’édition **2026**, la Coupe s’est déroulée du **13 au 16 mai 2026** au **Parc Expo Les Oudairies à La Roche-sur-Yon** (France).

Cette manifestation regroupe **plusieurs compétitions**, dont :
- La **Coupe de France de Robotique Senior**, où des équipes passionnées (étudiants, clubs, makers, etc.) présentent leurs robots autonomes,  
- L’épreuve **Eurobot**, volet international de la compétition,  
- Et la **Coupe de France de Robotique Junior**, destinée aux jeunes dès 7 ans.

Chaque robot doit être **entièrement autonome** et capable de réaliser une série de missions sur une surface de jeu définie dans le règlement autour d’un **thème annuel**, ici **“Winter is Coming”** — symbolisant la préparation de réserves pour l’hiver (écureuils, noisettes, collecte de ressources, etc.).

Les compétitions durent généralement **100 secondes**, et les robots marquent des points en accomplissant des objectifs techniques précis.
Chaque année, la table de jeu et les obstacles changent, demandant aux équipes d’innover et de s’adapter. Par exemple, en 2026 des éléments symboliques comme des **planches jaune et bleu**, un **nid**, un **grenier** et une petite **scène** ont été intégrés au terrain pour représenter différentes **zones de réserves**. *(Voir la documentation officielle)*

<div style="display: flex; justify-content: space-around; flex-wrap: wrap;">
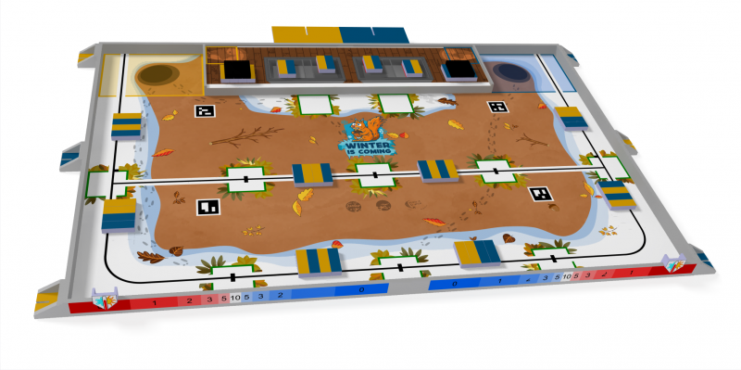
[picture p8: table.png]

</div>

## Une opportunité d'apprendre

### En s'amusant 

La compétition est **ouverte à tous** — étudiants, clubs scientifiques, associations ou passionnés de technologie. Elle permet de travailler concrètement sur un **projet complet** mêlant **mécanique, électronique, informatique** et **stratégie**. 

Au-delà de la performance technique, c’est aussi un lieu d’**échanges, de rencontres et de partage**, où les équipes peuvent découvrir d’autres projets, apprendre de nouvelles approches et vivre une **aventure humaine** forte.

### Et en se cassant la tête 

Participer à la Coupe de France de robotique permet de relever un vrai défi, de progresser dans de nombreux domaines et de vivre une expérience unique.

Pour bien comprendre l'envergure du challenge, il faut se pencher plus en détail sur les règles.

Eurobot 2026 impose un cadre technique, stratégique et logistique exigeant.

Chaque équipe doit concevoir un robot totalement autonome capable d’interagir avec des éléments du terrain dans un temps limité. Ses dimensions doivent être inférieures ou égales à 1200 mm en position repliée et inférieures ou égales à 1400 mm en position déployée. Toutes les normes de sécurité de base doivent être respectées, notamment en termes d’électricité.

De plus, un système anti-collision avec les robots adverses est obligatoire et doit être fonctionnel.

Le match, chronométré à 100 secondes, demande d’allier la rapidité et la coordination.

Les actions sont strictement encadrées : déplacement, collecte, positionnement d’objets, le tout sans contact avec l’adversaire comme détaillé ici :

<div style="display: flex; justify-content: space-around; flex-wrap: wrap;">
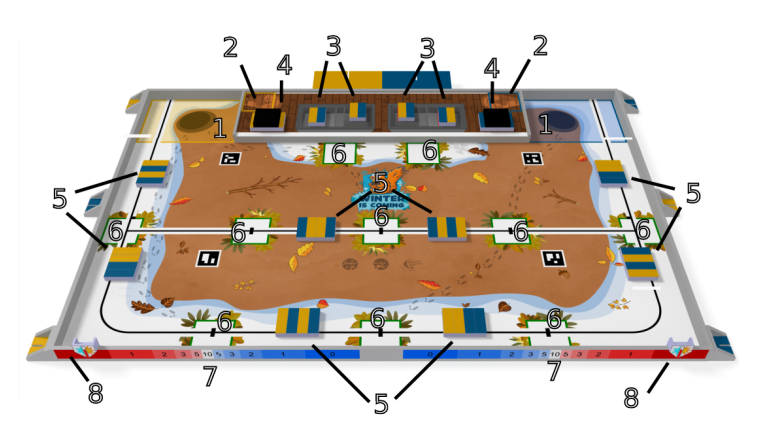
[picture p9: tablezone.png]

</div>
<div style="display: flex; justify-content: space-around; flex-wrap: wrap;">

</div>

La moindre erreur peut entraîner des pénalités, voire une disqualification. C’est un défi important qui repose sur notre esprit d’équipe et notre ingéniosité.

Ces règles sont à prendre en compte dès le début de notre réflexion, car notre robot doit passer ce que l'on appelle les homologations.

## L'homologation

Avant d’être autorisé à disputer un match, un robot doit être **homologué** par les référés :  
– Une **épreuve statique** pour vérifier les dimensions et la conformité aux règles de sécurité,  
– Une **épreuve dynamique** où le robot doit effectuer au minimum une action significative dans le temps imparti.  

Toute modification après validation doit être **signalée** et peut nécessiter une nouvelle homologation.

Lors de cette édition, "dire si homologation réussi et notre place au classement" de la [CDFR 2026]**.

## L’événement WE R’ TECH’

La Coupe de France de Robotique 2026 s’est intégrée au **festival WE R’ TECH’**, un événement riche mêlant compétition, ateliers, expositions et animations autour des sciences, de la technologie et de la robotique pour **tous les publics**, y compris les enfants.

Ce festival offre également aux visiteurs des **ateliers ludiques et pédagogiques gratuits ou sur inscription**, afin d’**éveiller la curiosité scientifique** des plus jeunes.

## Où et quand ?

**Coupe de France de Robotique 2026**  
📍 Parc Expo Les Oudairies — La Roche-sur-Yon, France  
📅 Du **13 au 16 mai 2026**  
🕘 De 09 h00 à 18 h00 (jours d’exposition)

[UniWIP]: https://github.com/orgs/Unimakers/teams/uniwip  
[CDFR 2026]: https://www.coupederobotique.fr/edition-2026/  
[Just The Docs]: https://just-the-docs.com/  
[Jekyll]: https://jekyllrb.com

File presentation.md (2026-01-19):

---
title: Présentation de l'équipe
layout: default
---
L’équipe UniMakers – Coupe de France de Robotique 2026 🤖

Nous sommes UniWIP, l’équipe robotique de l’association Unimakers de l’école UniLaSalle Amiens. 
Grâce au soutien de l’association, nous avons pu concevoir et réaliser nos différents robots pour participer à la Coupe de France de Robotique !
Notre équipe, soudée et passionnée, s’est engagée cette année dans l’incroyable aventure de la Coupe de France de Robotique.
Chacun a mis ses compétences, sa créativité et son énergie au service d’un projet commun : concevoir, construire et faire concourir un robot capable de relever tous les défis du règlement 2025.

Voici les membres qui ont fait vivre ce projet :

Oscar : chef d'équipe, responsable méchanique et éléctronique

Aurélien : responsable programation 

Ellyn

Matthieu 

Owen
 
Alexandre

Bastian

Jade

Paul

Une équipe soudée, inventive et toujours prête à relever les défis ! 🚀

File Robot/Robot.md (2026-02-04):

---
title: "Robot"
nav_order: 1
layout: technical
---
## Le robot principal 🤖
❌ **La suite de cette documentation n'est pas à jour.**

<model-viewer alt="ROBOT" src="./Meca/FichiersGLTF/ExportRobotUniWIP.glb" ar style="width:80%; height:400px" shadow-intensity="1" camera-controls min-field-of-view="2deg"></model-viewer>

## Les Objectifs

Le robot est le premier à effectuer des actions lors d'un match. Cette année on pouvait compter 2 actions principales :

<div style="display: flex; justify-content: space-around; flex-wrap: wrap;">


</div>

La première était de déployer une banderole conçue par l'équipe, avec comme contrainte de se déployer à l'avant de la table définie par la couleur de notre équipe.

La seconde consiste à prendre des planches et des conserves placées précisément sur la table, afin de les amener dans une zone de construction définie pour construire des gradins d'un ou plusieurs étages.

À la fin du match, le robot doit terminer sa trajectoire dans une zone à l'arrière de la table définie encore une fois par la couleur de notre équipe.

## Contraintes

Le robot est autorisé à :

- Manipuler les éléments de jeux (conserves et planches).
- déployer une bannière embarquée.

Le robot n'est pas autorisé à :

- Nuire à l'adversaire.
- Détruire des constructions adverses.
- Voler des conserves dans la zone réservée à l'adversaire.
- Dépasser la hauteur maximale en dehors des zones de constructions.

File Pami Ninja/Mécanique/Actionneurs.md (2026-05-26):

---
title: "Actionneurs"
layout: technical
grand_parent: Pami Ninja
parent: Mécanique
has_children: false
---

# Section actionneur : bras ventouse

## 1. Présentation générale 

L'actionneur principal du *PAMI* est conçu pour la manipulation rapide et sécurisée des caisses de noisettes. Pour maximiser l'efficacité lors des matchs, nous avons opté pour un système de préhension par le vide monté sur un *bras articulé*. Ce choix permet une saisie robuste malgré les vibrations du robot, tout en conservant une grande simplicité de pilotage logiciel (tout ou rien pour la pompe).

## 2. Architecture mécanique 

Le système se compose d'un bras à segment, permettant une grande liberté de mouvement tout en restant dans le périmètre de départ du PAMI (150x150mm).

* **Le bras :** Articulé via un servomoteur, permettant d'ajuster l'inclinaison pour atteindre les caisses.

* **La tête :** Une pièce imprimée en 3D permettant de supporter une ventouse, elle est creusée par un scillion amenant l'air à cette dernière. L'étanchéité interne est assurée par une épaisseur de paroi augmentée lors de l'impression.

* **La ventouse :** L'utilisation d'un seule ventouse souple permet de prendre la caisse en s'adaptant aux éventuels défauts de parallélisme entre le robot et la cible.

Le bras vient acceuillir en son creux un tuyau reliant la ventouse à la pompe. Le tuyau esr donc protégé des élements extérieurs pour éviter qu'il se décroche ou qu'il ne s'emmêle dans la structure en profilés lors des mouvements.

## 3. Système pneumatique

La dépression est générée par une micro-pompe à vide logée au centre du châssis. 

Le circuit est volontairement court pour réduire le volume d'air à pomper, ce qui permet une préhension quasi instantanée dès que la ventouse entre en contact avec la paroi de la caisse.

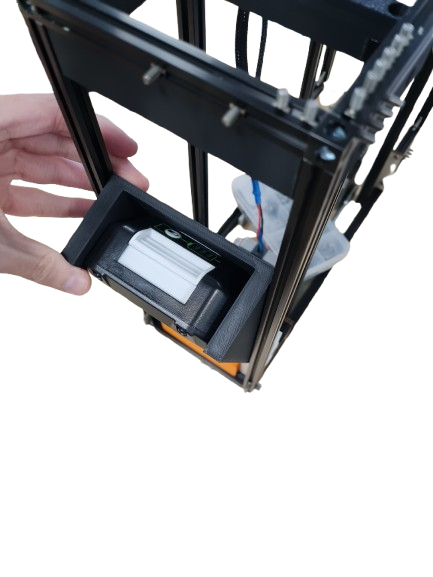
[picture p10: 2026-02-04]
Robot/Meca/Images/Pivot_Batterie.png

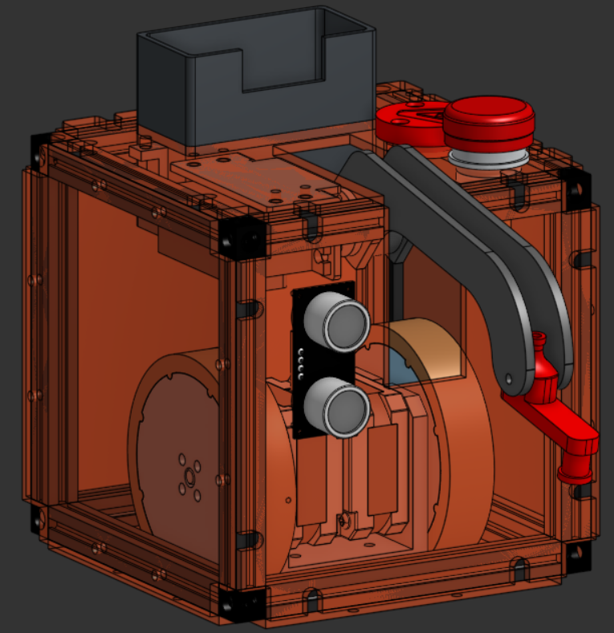
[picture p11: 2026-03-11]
Pami Ninja/Mécanique/pami-ninja.PNG

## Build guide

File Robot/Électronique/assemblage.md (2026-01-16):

---
title: "La réalisation de la carte"
parent: Elec
layout: technical
---

## 6. Nomenclature (BOM) ( doc a part avec fabrication et assemblage)
- Tableau des composants
  - Référence
  - Désignation
  - Valeur
  - Boîtier
  - Quantité
- Composants critiques

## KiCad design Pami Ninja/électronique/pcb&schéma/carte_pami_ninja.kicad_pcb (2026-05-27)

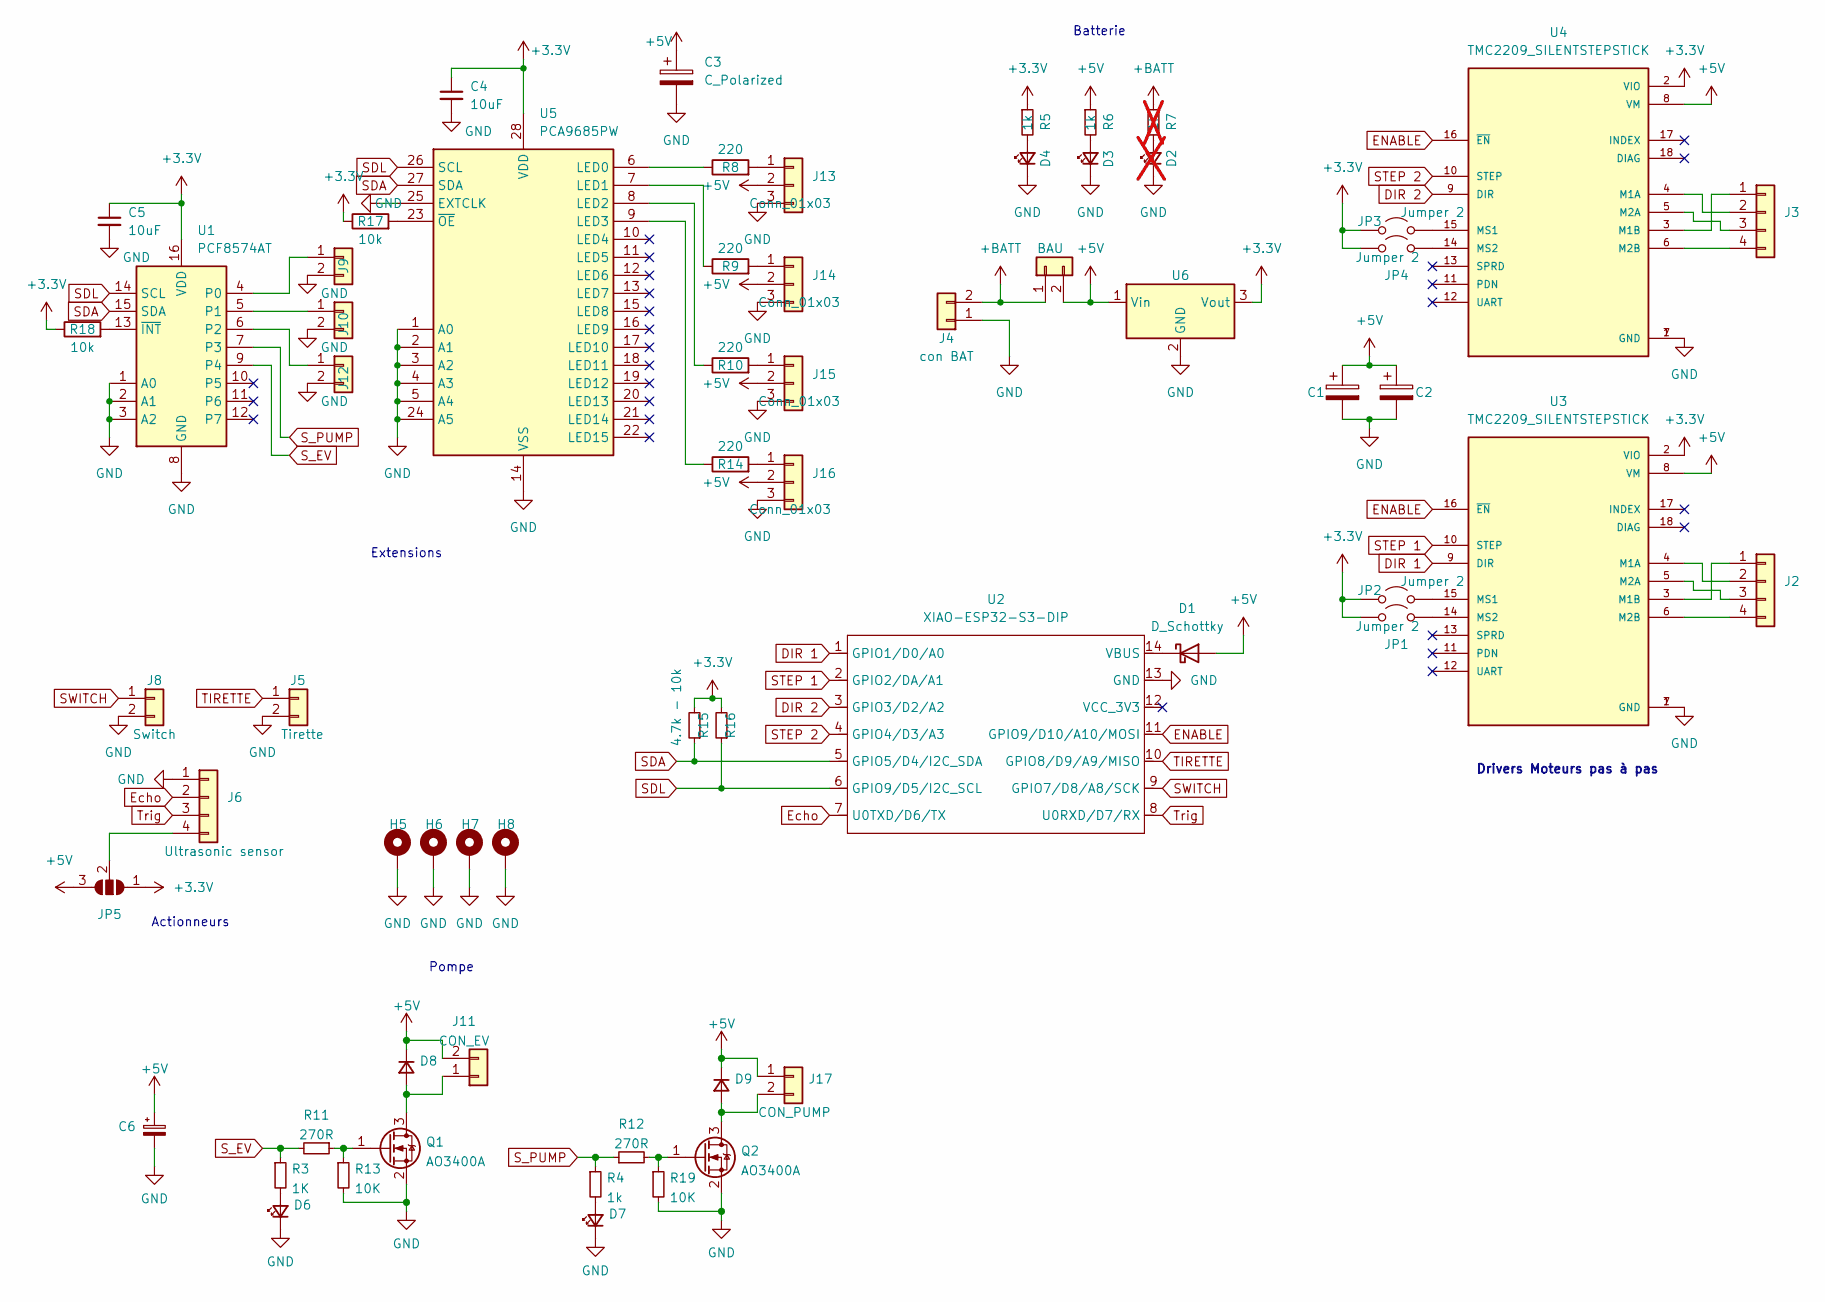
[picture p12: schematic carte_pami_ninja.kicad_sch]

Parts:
C1, C2: C_Polarized; CP_Radial_D8.0mm_P3.80mm
C3: C_Polarized; CP_Radial_D8.0mm_P5.00mm
C4, C5: 10uF; C_1206_3216Metric_Pad1.33x1.80mm_HandSolder
C6: C_Polarized_Small; CP_Radial_D8.0mm_P5.00mm
D1: D_Schottky; D_DO-41_SOD81_P10.16mm_Horizontal
D2: LED_Small; LED_1206_3216Metric_Pad1.42x1.75mm_HandSolder; not fitted
D3, D4, D6, D7: LED_Small; LED_1206_3216Metric_Pad1.42x1.75mm_HandSolder
D8, D9: D_Small; D_SMA_Handsoldering
H5, H6, H7, H8: MountingHole_3.2mm_M3_Pad
J1: BAU; Molex_KK-254_AE-6410-02A_1x02_P2.54mm_Vertical
J2, J3: Conn_01x04; Molex_KK-254_AE-6410-04A_1x04_P2.54mm_Vertical
J4: con BAT; AMASS_XT60-F_1x02_P7.20mm_Vertical
J5: Tirette; Molex_KK-254_AE-6410-02A_1x02_P2.54mm_Vertical
J6: Ultrasonic sensor; Molex_KK-254_AE-6410-04A_1x04_P2.54mm_Vertical
J8: Switch; Molex_KK-254_AE-6410-02A_1x02_P2.54mm_Vertical
J9, J10, J12: Conn_01x02; Molex_KK-254_AE-6410-02A_1x02_P2.54mm_Vertical
J11: CON_EV; Molex_KK-254_AE-6410-02A_1x02_P2.54mm_Vertical
J13, J14, J15, J16: Conn_01x03; PinHeader_1x03_P2.54mm_Vertical
J17: CON_PUMP; Molex_KK-254_AE-6410-02A_1x02_P2.54mm_Vertical
JP1, JP2, JP3, JP4: Jumper 2; SolderJumper-2_P1.3mm_Open_RoundedPad1.0x1.5mm
JP5: SolderJumper_3_Open; SolderJumper-3_P1.3mm_Open_RoundedPad1.0x1.5mm_NumberLabels
Q1, Q2: AO3400A; SOT-23
R3: 1K; R_1206_3216Metric_Pad1.30x1.75mm_HandSolder
R4, R5, R6: 1k; R_1206_3216Metric_Pad1.30x1.75mm_HandSolder
R7: 1k; R_1206_3216Metric_Pad1.30x1.75mm_HandSolder; not fitted
R8, R9, R10, R14: 220; R_1206_3216Metric_Pad1.30x1.75mm_HandSolder
R11, R12: 270R; R_1206_3216Metric_Pad1.30x1.75mm_HandSolder
R13, R19: 10K; R_1206_3216Metric_Pad1.30x1.75mm_HandSolder
R15: 4.7k - 10k; R_1206_3216Metric_Pad1.30x1.75mm_HandSolder
R16: R_Small; R_1206_3216Metric_Pad1.30x1.75mm_HandSolder
R17, R18: 10k; R_1206_3216Metric_Pad1.30x1.75mm_HandSolder
U1: PCF8574AT; SOIC-16W_7.5x10.3mm_P1.27mm
U2: XIAO-ESP32-S3-DIP; XIAO-ESP32S3-DIP
U3, U4: TMC2209_SILENTSTEPSTICK; MODULE_TMC2209_SILENTSTEPSTICK; PARTREV 1.20
U5: PCA9685PW; TSSOP-28_4.4x9.7mm_P0.65mm
U6: TSR1-2433E; Converter_DCDC_TRACO_TSR1-xxxxE_THT

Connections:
+3.3V: C4.1, C5.1, JP1.1 (A), JP2.1 (A), JP3.1 (A), JP4.1 (A), JP5.1 (A), R5.1, R15.2, R16.2, R17.1, R18.1, U1.16 (VDD), U3.2 (VIO), U4.2 (VIO), U5.28 (VDD), U6.3 (Vout)
+5V: C1.1, C2.1, C3.1, C6.1, D1.2 (A), D8.1 (K), D9.1 (K), J1.2, J11.2, J13.2, J14.2, J15.2, J16.2, J17.1, JP5.3 (B), R6.1, U3.8 (VM), U4.8 (VM), U6.1 (Vin)
+BATT: J1.1, J4.2, R7.1
DIR 1: U2.1 (GPIO1/D0/A0), U3.9 (DIR)
DIR 2: U2.3 (GPIO3/D2/A2), U4.9 (DIR)
ENABLE: U2.11 (GPIO9/D10/A10/MOSI), U3.16 (~EN), U4.16 (~EN)
Echo: J6.2, U2.7 (U0TXD/D6/TX)
GND: C1.2, C2.2, C3.2, C4.2, C5.2, C6.2, D2.1 (K), D3.1 (K), D4.1 (K), D6.1 (K), D7.1 (K), H5.1, H6.1, H7.1, H8.1, J4.1, J5.2, J6.1, J8.2, J9.2, J10.2, J12.2, J13.3, J14.3, J15.3, J16.3, Q1.2 (S), Q2.2 (S), R13.2, R19.2, U1.1 (A0), U1.2 (A1), U1.3 (A2), U1.8 (GND), U2.13 (GND), U3.1 (GND), U3.7 (GND), U4.1 (GND), U4.7 (GND), U5.1 (A0), U5.2 (A1), U5.3 (A2), U5.4 (A3), U5.5 (A4), U5.14 (VSS), U5.24 (A5), U5.25 (EXTCLK), U6.2 (GND)
unnamed: D1.1 (K), U2.14 (VBUS)
unnamed: D2.2 (A), R7.2
unnamed: D3.2 (A), R6.2
unnamed: D4.2 (A), R5.2
unnamed: D6.2 (A), R3.2
unnamed: D7.2 (A), R4.2
unnamed: D8.2 (A), J11.1, Q1.3 (D)
unnamed: D9.2 (A), J17.2, Q2.3 (D)
unnamed: J2.1, U3.3 (M1B)
unnamed: J2.2, U3.4 (M1A)
unnamed: J2.3, U3.5 (M2A)
unnamed: J2.4, U3.6 (M2B)
unnamed: J3.1, U4.3 (M1B)
unnamed: J3.2, U4.4 (M1A)
unnamed: J3.3, U4.5 (M2A)
unnamed: J3.4, U4.6 (M2B)
unnamed: J6.4, JP5.2 (C)
unnamed: J9.1, U1.4 (P0)
unnamed: J10.1, U1.5 (P1)
unnamed: J12.1, U1.6 (P2)
unnamed: J13.1, R8.2
unnamed: J14.1, R9.2
unnamed: J15.1, R10.2
unnamed: J16.1, R14.2
unnamed: JP1.2 (B), U3.14 (MS2)
unnamed: JP2.2 (B), U3.15 (MS1)
unnamed: JP3.2 (B), U4.15 (MS1)
unnamed: JP4.2 (B), U4.14 (MS2)
unnamed: Q1.1 (G), R11.1, R13.1
unnamed: Q2.1 (G), R12.2, R19.1
unnamed: R18.2, U1.13 (~INT)
unnamed: R8.1, U5.6 (LED0)
unnamed: R9.1, U5.7 (LED1)
unnamed: R10.1, U5.8 (LED2)
unnamed: R14.1, U5.9 (LED3)
unnamed: R17.2, U5.23 (~OE)
SDA: R15.1, U1.15 (SDA), U2.5 (GPIO5/D4/I2C_SDA), U5.27 (SDA)
SDL: R16.1, U1.14 (SCL), U2.6 (GPIO9/D5/I2C_SCL), U5.26 (SCL)
STEP 1: U2.2 (GPIO2/DA/A1), U3.10 (STEP)
STEP 2: U2.4 (GPIO4/D3/A3), U4.10 (STEP)
SWITCH: J8.1, U2.9 (GPIO7/D8/A8/SCK)
S_EV: R3.1, R11.2, U1.9 (P4)
S_PUMP: R4.1, R12.1, U1.7 (P3)
TIRETTE: J5.1, U2.10 (GPIO8/D9/A9/MISO)
Trig: J6.3, U2.8 (U0RXD/D7/RX)

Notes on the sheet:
Batterie
Pompe
Actionneurs
Drivers Moteurs pas à pas
Extensions

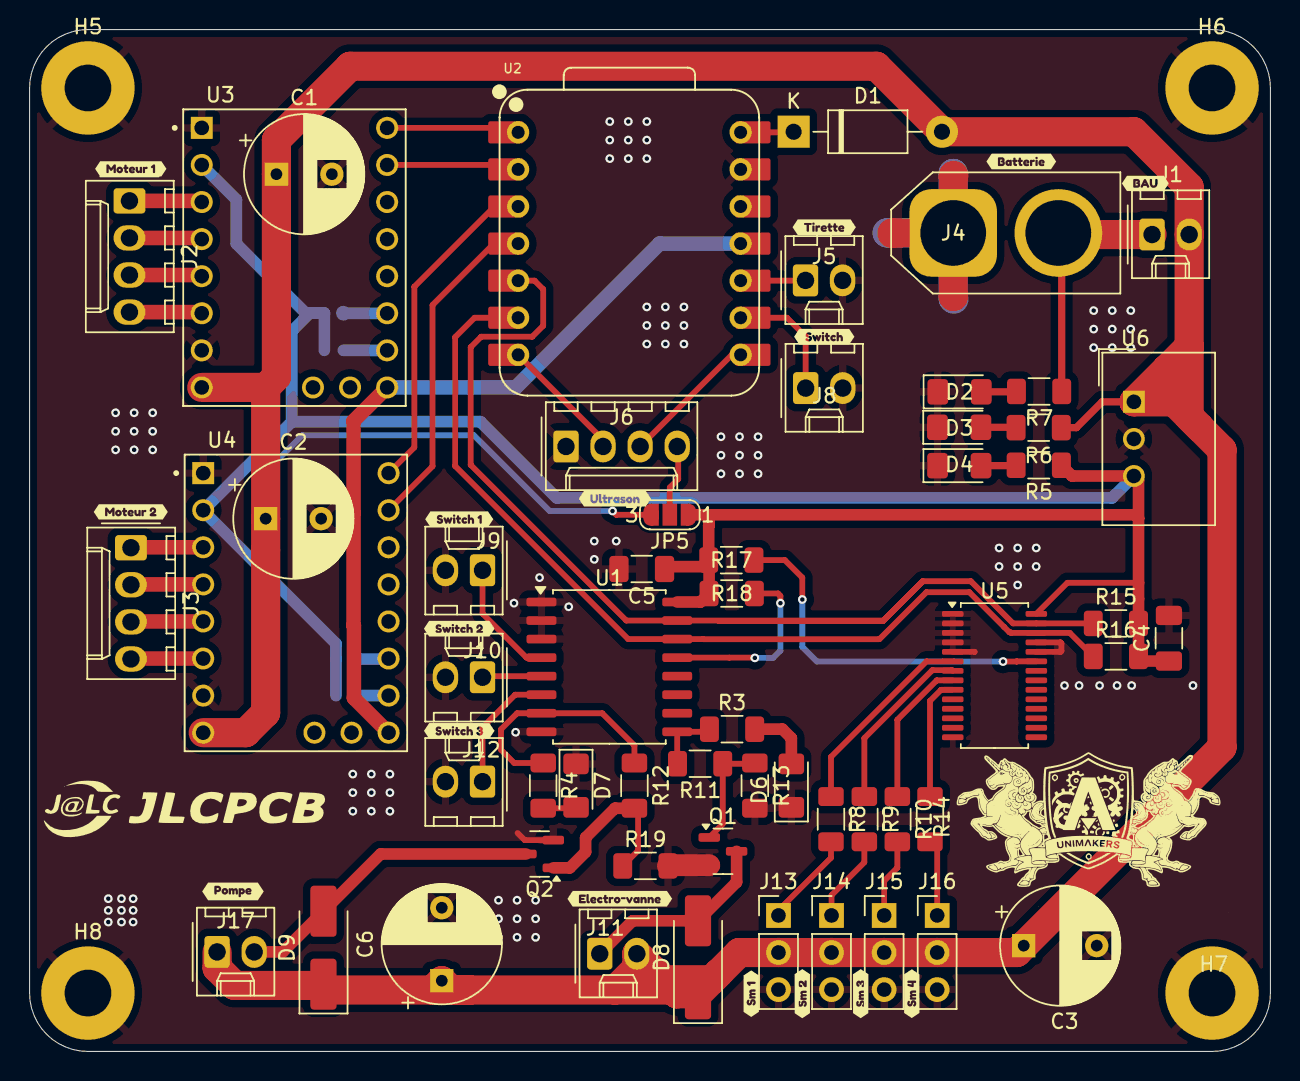
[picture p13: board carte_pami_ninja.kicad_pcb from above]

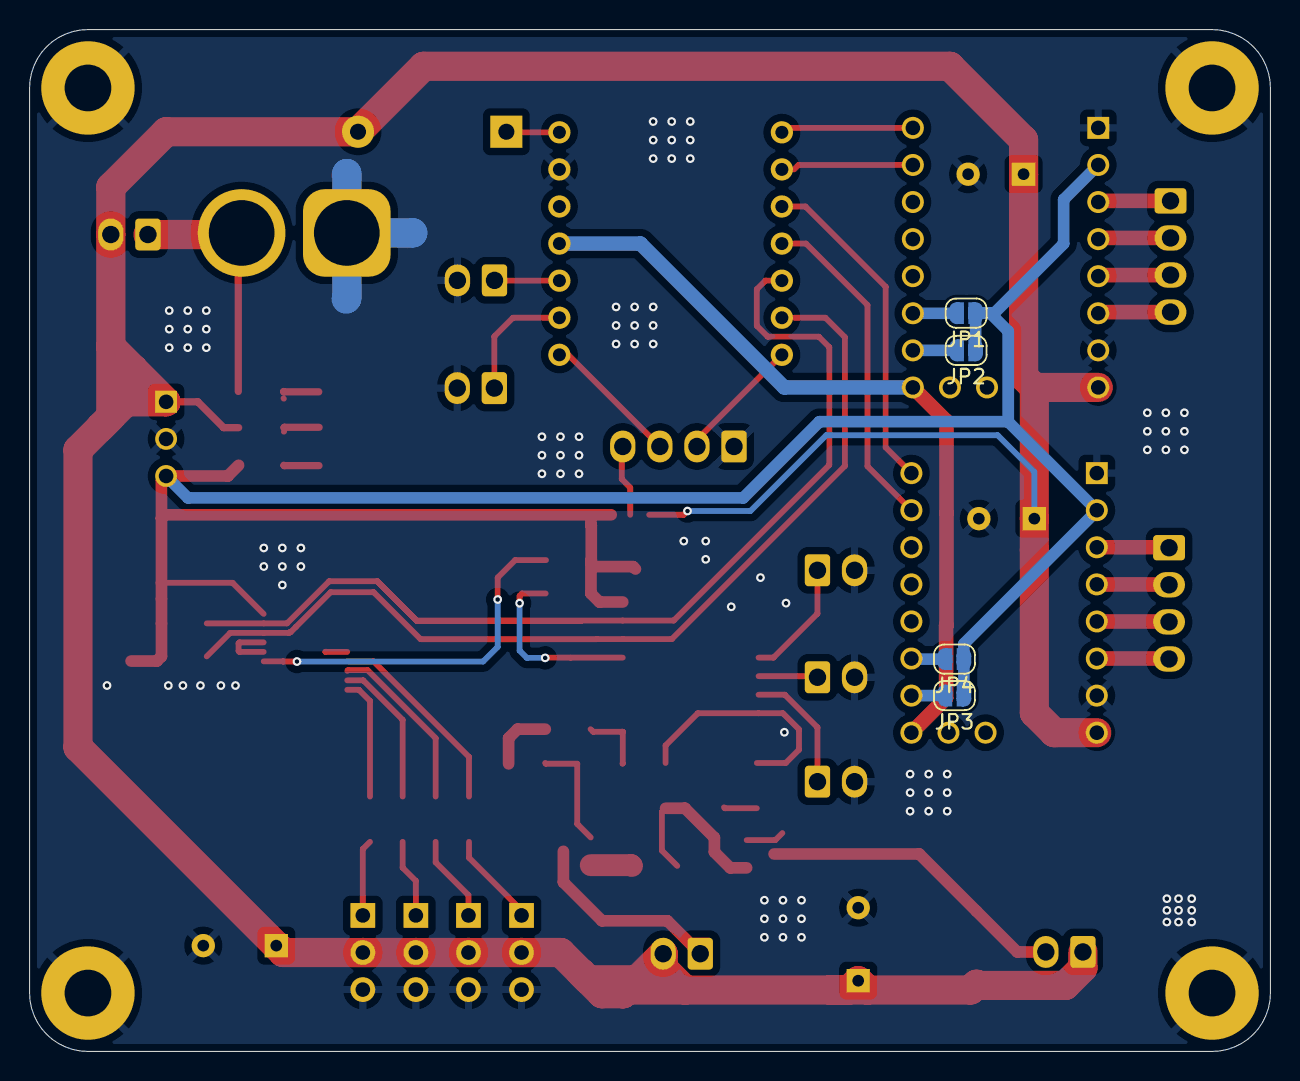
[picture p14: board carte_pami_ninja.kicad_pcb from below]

Board: 2 copper layers, 85.0 x 70.0 mm, 80 parts (4 on the bottom side), 53 nets.

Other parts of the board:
kibuzzard-69BD4C51: G***; kibuzzard-69BD4C51
kibuzzard-69BD4C98: G***; kibuzzard-69BD4C98
kibuzzard-69BD4CAE: G***; kibuzzard-69BD4CAE
kibuzzard-69BD4CC4: G***; kibuzzard-69BD4CC4
kibuzzard-69BD4CEF: G***; kibuzzard-69BD4CEF
kibuzzard-69BD4D3C: G***; kibuzzard-69BD4D3C
kibuzzard-69BD4D5C: G***; kibuzzard-69BD4D5C
kibuzzard-69BD4D83: G***; kibuzzard-69BD4D83
kibuzzard-69BD4D93: G***; kibuzzard-69BD4D93
kibuzzard-69BD4EA4: G***; kibuzzard-69BD4EA4
kibuzzard-69BD4EB4: G***; kibuzzard-69BD4EB4
kibuzzard-69BD4EFE: G***; kibuzzard-69BD4EFE
kibuzzard-69BD4FA7: G***; kibuzzard-69BD4FA7
kibuzzard-69BD4FC7: G***; kibuzzard-69BD4FC7
kibuzzard-69BD4FD6: G***; kibuzzard-69BD4FD6
kibuzzard-69BD4FE1: G***; kibuzzard-69BD4FE1

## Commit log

2026-01-20 test pcb
    [doom v1.kicad_sch]
2026-01-21 début edit de la presentation de la coupe
2026-04-20 update txt et syst pneumatique
    Updated the actuator section with additional details on the mechanical architecture and pneumatic system. Improved clarity and added information on the design choices and functionality.
2026-05-27 assemblage pami ninja
2026-05-27 ajout pcb et schématique
    [carte_pami_ninja.kicad_pcb, carte_pami_ninja.kicad_sch]
